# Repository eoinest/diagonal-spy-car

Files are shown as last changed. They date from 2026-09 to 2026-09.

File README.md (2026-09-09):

# Diagonal Spy Car

An open-source, 3D-printable rover using two owned MG90S-style continuous servos, a LOLIN ESP32-S2 Mini, and diagonal drive wheels. Inspired by [Pro Know DIY's micro RC FPV car](https://github.com/proknowdiy/micro_rc_fpv_car_esp-now).

## Complete Blender assembly - revision 0.6.2

Open the [complete Blender model](cad/complete/complete-spy-car.blend) for assembled and exploded scenes, detailed component references, routed wiring, and the removable electronics carrier. The battery, owned large buck and S2 Mini fit in one layer on a **52 x 76 mm deck**. The integral printed axles are preserved. The simplified revision removes the battery-sensing perfboard, its transistors/resistors, ADC capacitor, signal wiring and printed holder. The fuse, small 100 nF S2 bypass and positive-only `J_PWR` remain. Revision 0.6.2 removes the extra 220 µF capacitor, its wires and printed holder. Battery checks are manual; there is no onboard voltage monitoring or low-voltage stop. Revision 0.6.1 corrects the fuse to a rounded epoxy profile and adds axial lead clearances to its holder.

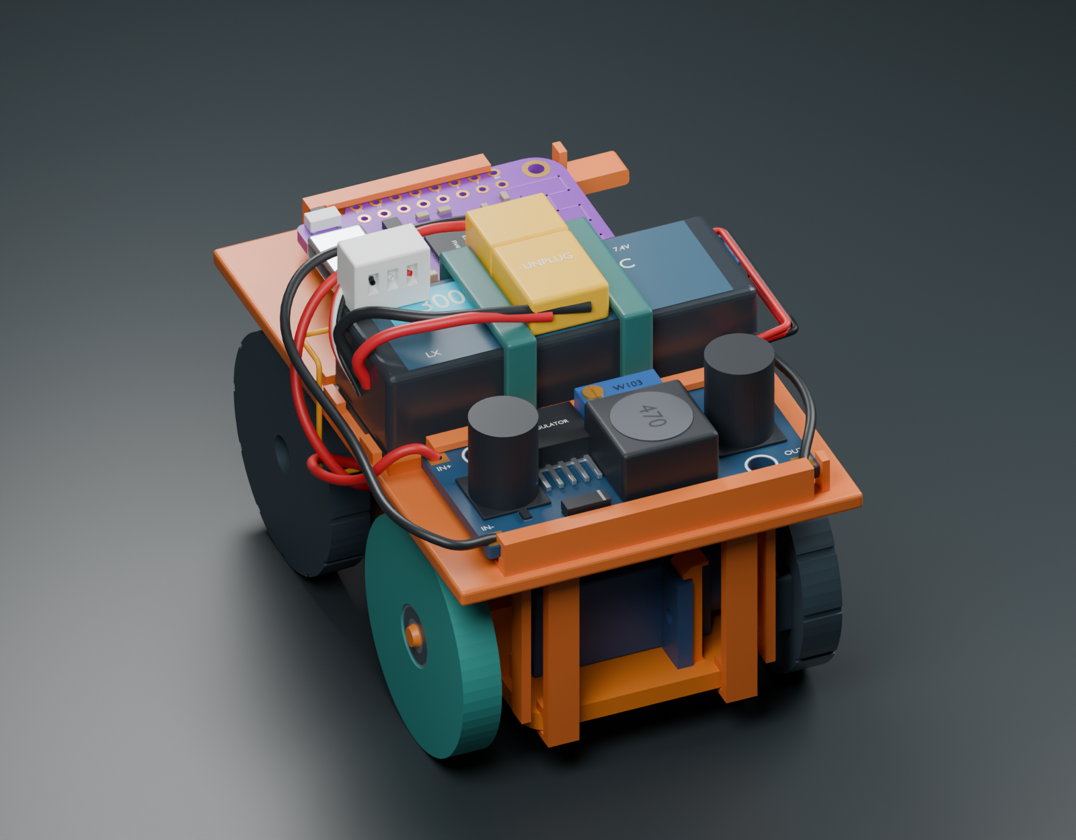
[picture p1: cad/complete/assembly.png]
Complete camera-free car


Get the [new printed parts and assembly instructions](cad/complete/README.md), [dimension assumptions and sources](cad/complete/README.md#what-is-accurate-and-what-still-needs-measurement), and [geometry validation report](cad/complete/validation.json). This is a complete nominal prototype; the owned buck, servo and horn geometry still requires measurements.

## Picture wiring guide and current electronics

Use the [seven-page illustrated wiring PDF](output/pdf/spy-car-wiring-guide.pdf), [step-by-step wiring notes](electronics/wiring.md), and [camera-free electronics BOM](electronics/camera-free-bom.csv). This revision selects the owned large LM2596-style buck at 5.00 V and a Lumenier 300 mAh 2S XT30 battery (48 x 17 x 12 mm). Converter identity and loaded performance still need confirmation; neither owned board supplies LiPo charging or cutoff. The guide includes exact S2 pad callouts, manual per-cell battery checks, USB isolation and connector matching.

**Routine firmware updates use Espressif's bundled HTTPUpdateServer:** after one USB installation and private password setup, hold the S2 Mini's BOOT/0 button for three seconds after normal startup, join `SpyCar-Update`, and upload the receiver application at `http://192.168.4.1/update`. Driving stays locked during updates. No extra power switch or onboard hardware is needed; USB remains for initial setup and recovery. Read the [wireless update instructions and bench verification limits](firmware/README.md#wireless-receiver-updates). This feature is software-tested, not yet verified on the physical car.

## Browser joystick remote

The S2 Mini now serves a simple phone or desktop joystick at **http://spy-car.local/** using the same existing-Wi-Fi + mDNS approach as auto-switch. Hold and drag for proportional forward/reverse, curved turns and spins; release to stop. An optional **SpyCar** Wi-Fi network works away from your router. No app, internet service or second ESP32 is required. The existing handheld remains an optional firmware mode.

Read the [network setup, calibration and testing instructions](firmware/README.md#browser-remote-control). Software and simulated browser checks pass; actual networking and servo behavior still require a wheels-raised test on the car. Firmware defaults keep motion disabled until servo calibration is confirmed.

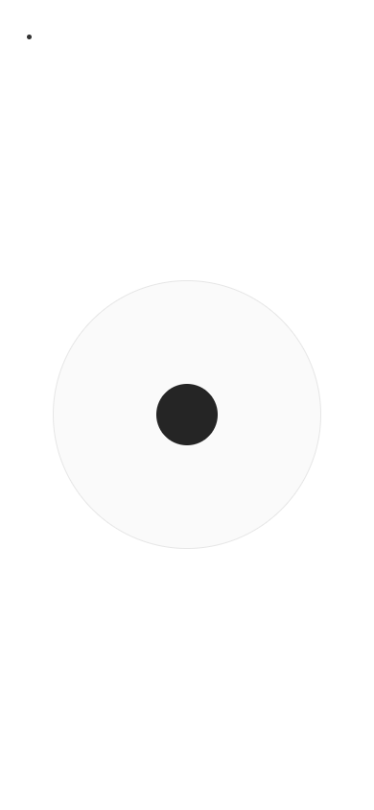
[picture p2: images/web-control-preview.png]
Phone joystick preview using simulated car telemetry


## Earlier mechanical stage: integral printed axles

The latest [revision 0.4 model](cad/rolling/README.md) makes both passive-wheel axles **part of the printed chassis**, with integral shoulders and servo retaining clips. Bearings press-fit into the wheels and onto the stationary pegs. There are **no added screws, nuts, caps or separate spacers** in this mechanical stage: only the owned servos and two MR83ZZ bearings are purchased parts.

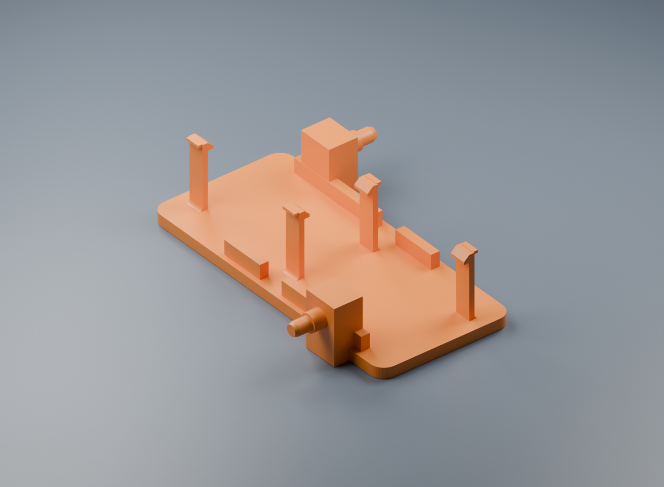
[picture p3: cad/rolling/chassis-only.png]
Chassis with integral printed axles


Open the [wheel-only Blender model](cad/rolling/rolling-chassis.blend), get the [chassis, wheel and two fit-coupon STLs](cad/rolling/README.md), or review [the simplified bearing parts list](docs/passive-wheel-parts.md). The illustrated footprint is approximately **50 × 70 mm** with 30 mm wheels. Printed friction fits and clips need physical validation; the powered wheels remain size envelopes pending their horn attachments.

## Previous step: compact servo bracket

The current direction drops the camera and places the two servo bodies directly alongside each other, with one rotated 180 degrees so their shafts emerge at diagonal corners. The first model is a **30 × 66 mm one-piece bracket** with four mounting-ear screw points. It is a nominal fit prototype; measure the owned servos before relying on the hole positions.

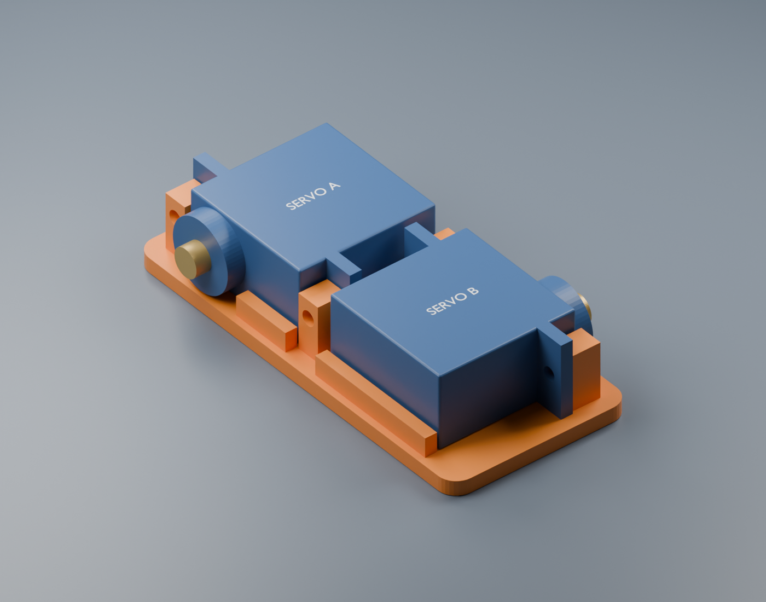
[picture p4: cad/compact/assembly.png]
Compact opposing servo pair


Open the [Blender model](cad/compact/servo-pair.blend), download the [bracket STL](cad/compact/servo-pair-bracket.stl), or read the [compact model notes and parameters](cad/compact/README.md). The [camera-free battery and regulator shortlist](docs/compact-shopping.md) supports the next electronics-layout step. This first bracket has no electronics deck or wheel mounts yet; the complete camera-free assembly above supersedes this first bracket.

## Archived early concept

The original camera-equipped revision used different batteries, regulators and power monitoring. Its [CAD](cad/diagonal-spy-car.blend), [BOM](BOM.md), and [power research](docs/power.md) are historical references. Build from the current [complete assembly instructions](cad/complete/README.md), [electronics BOM](electronics/camera-free-bom.csv), and [firmware instructions](firmware/README.md).

## Rebuilding the current assembly

Follow the [complete assembly rebuild and verification instructions](cad/complete/README.md#rebuild-and-verification). The build scripts regenerate the deck STL and model; `power_update.py` then applies the fuse, connector and harness details and renders the current views. Fit, electrical loading and actual driving still require physical prototype checks.

## License and provenance

Original CAD, scripts, firmware and documentation are released under the **[MIT License](LICENSE)**. Brand names identify compatible purchased parts; no affiliation or endorsement is claimed. This is an original design inspired by the linked project; no upstream code, meshes or PCB files are redistributed. Source links identify which dimensions are published and which are assumptions. See [third-party notes](THIRD_PARTY.md).

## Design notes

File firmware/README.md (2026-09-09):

# Firmware: browser joystick and wireless updates

Original MIT-licensed prototype firmware for an ESP32-S2 Mini car. The car hosts a touch/mouse joystick at **http://spy-car.local/**, with no app, internet connection, or second ESP32 needed. The previous ESP-NOW handheld remains an optional build mode. A separate parked Wi-Fi mode provides browser firmware updates. Arduino-ESP32 **3.x** is required; the LEDC API differs from 2.x. No code from the inspiration repository was copied.

The checked-in configuration cannot arm. Configure Wi-Fi and measure servo neutral first. This simplified POC has no battery-sensing circuit: check both cells with a multimeter before and between short, attended runs. Firmware provides no low-voltage warning or cutoff. Pairing keys, MAC addresses and analog joystick calibration are needed only for the optional handheld. Firmware compilation and host tests do not validate wiring, servo behavior, RF performance, or battery protection on real hardware.

## Browser remote control

This follows the auto-switch project's **existing Wi-Fi + mDNS** arrangement: a readable `.local` name points to the device on the same network. The car uses Espressif's bundled `esp_http_server` WebSocket support and `ESPmDNS`; the page is plain HTML, CSS and JavaScript embedded in the firmware. No extra server, filesystem upload or third-party Arduino library is required.

### Network setup

1. Copy `firmware/receiver_s2/web_config.h` to `web.private.h` in the same folder. Keep `WEB_CONTROL_ENABLED = true` and `WEB_HOSTNAME = "spy-car"`.
2. For the auto-switch arrangement, set `WEB_WIFI_SSID` and `WEB_WIFI_PASSWORD` to your existing **2.4 GHz** Wi-Fi. Connect your phone to that same network, then open **http://spy-car.local/**. If mDNS does not resolve, use the numeric address printed to the receiver's serial console at 115200 baud. Router client isolation and VPNs can prevent access.
3. Alternatively, leave `WEB_WIFI_SSID` empty to create the standalone **SpyCar** network. Set the private `OTA_PASSWORD` as described below, join SpyCar using that password, and open **http://192.168.4.1/** (or the `.local` name where supported). Stay connected when your phone reports no internet. A configured but unavailable home network does not automatically fall back to this AP; select the mode before building.
4. Keep `web.private.h`, `ota.private.h` and the receiver's `config.private.h` with every build. They are ignored by Git and compiled into the application. Do not publish them.

The standalone AP shares its password with the separate update AP. Existing-network mode uses your router's Wi-Fi password instead. The drive page has no login: use a trusted network, because anyone on that network who opens the page can control the car when the controller slot is free. Origin checks and a page token prevent cross-site command injection; they are not user authentication.

### Driving

Hold the joystick and drag. The page first exchanges centered commands to arm, then follows the held gesture. Release to stop; leaving the page or losing the connection also cancels the gesture. Reconnecting never resumes a previous drag. Only one browser can own control at a time; close its tab before switching phones. A vanished controller can be replaced after two seconds without accepted commands.

| Joystick direction | Left powered wheel | Right powered wheel |
| --- | --- | --- |
| Forward / backward | Forward / backward | Forward / backward |
| Right | Forward | Backward |
| Left | Backward | Forward |
| Forward-right | Forward | Slower forward, reaching zero at 45° |
| Center or released | Neutral | Neutral |

Distance from center sets the requested speed, with a 6% center deadzone. The mixer uses `left = y + x`, `right = y - x`, normalizes both together, then applies radial speed. This covers the full circle without calculating an angle. Wheel commands are bounded and retain the conservative PWM range and acceleration ramp. Continuous-rotation servos do not report actual wheel speed: equal commands may drift, and this is not PID speed control.

The browser exchanges commands about every 50 ms with only one normal command awaiting acknowledgment. Each server challenge is single-use and expires after 200 ms; command age starts when that challenge was issued, so delayed TCP traffic cannot masquerade as fresh input. The drive loop disarms after 250 ms without a valid command and runs at a higher task priority than the HTTP server. Explicit stops bypass the movement queue; controller session changes invalidate old queued commands. These are software stop requests, not a certified stopping-time guarantee or a power disconnect.

### First drive and verification

Start with servo power disconnected. Set up the network and confirm the page opens. Copy receiver `config.h` to `config.private.h`; perform the servo-neutral calibration in commissioning steps **4–5** below. The browser shows the missing servo calibration and stays disabled until it is confirmed. No ADC calibration or perfboard is required; GPIO3 and GPIO7 remain unconnected. The minimal page shows connection status, with no battery-voltage readout.

Upload the configured receiver, raise the wheels, and verify forward/reverse, both spins, gradual speed changes and immediate neutral on release. Check a hidden tab, phone Wi-Fi loss, reconnection requiring a fresh gesture, a second browser, and maintenance-mode inhibition. Finally make a slow floor test. The diagonal wheel arrangement still needs sideways tire scrub to turn.

Software verification includes host protocol/gate tests, 15 browser-controller unit cases, phone and desktop layout checks, simulated WebSocket pointer interactions, and an Arduino-ESP32 3.3.11 compile. **The actual ESP32 HTTP/WebSocket service, phone networking and physical servo stopping remain untested on hardware.**

To edit the page, change `receiver_s2/web/`, run `python3 scripts/embed_web_control.py` from the repository root, then rebuild the receiver. `web_assets.h` is generated and committed so Arduino users can build without Python.

To use the previous handheld instead, set `WEB_CONTROL_ENABLED = false` in `web.private.h` and complete all legacy commissioning steps. Browser driving and ESP-NOW driving are mutually exclusive; parked OTA works with either.

## Hardware

| Board | Pin | Connection |
| --- | --- | --- |
| S2 mini | GPIO16 | Left continuous-rotation servo signal |
| S2 mini | GPIO18 | Right continuous-rotation servo signal |
| Original ESP32 DevKit | GPIO32 | Joystick throttle wiper |
| Original ESP32 DevKit | GPIO33 | Joystick steering wiper |
| Original ESP32 DevKit | GPIO27 | Normally-open deadman button to GND; internal pull-up |

The three DevKit connections above are only for the optional handheld. Power its joystick from **3.3 V**, connect grounds, and keep all analog input voltages in range. Servo power comes from the regulated servo rail, never from an ESP GPIO or its 3.3 V pin. See [wiring](../electronics/wiring.md) for the complete power path. No battery divider or sense gate is fitted in this simplified build; do not connect the LiPo directly to a GPIO.

## Build

Install Arduino CLI and the Espressif board package using its [official instructions](https://docs.espressif.com/projects/arduino-esp32/en/latest/installing.html). These commands are run from the repository root. The commands below pin core 3.3.11 for reproducibility; a different 3.x version must be rebuilt and tested.

```sh
arduino-cli core update-index --additional-urls https://espressif.github.io/arduino-esp32/package_esp32_index.json
arduino-cli core install esp32:esp32@3.3.11 --additional-urls https://espressif.github.io/arduino-esp32/package_esp32_index.json
arduino-cli compile --fqbn esp32:esp32:lolin_s2_mini:PartitionScheme=default --libraries firmware/libraries --output-dir firmware/build/receiver_s2 firmware/receiver_s2
arduino-cli compile --fqbn esp32:esp32:esp32 --libraries firmware/libraries firmware/transmitter_esp32
arduino-cli compile --fqbn esp32:esp32:lolin_s2_mini firmware/servo_neutral_s2
```

For Arduino IDE, copy `firmware/libraries/SpyCarProtocol` into the sketchbook `libraries` directory, open the desired `.ino`, select **LOLIN S2 MINI** for the receiver/calibration tool or **ESP32 Dev Module** for the transmitter, and build. If USB serial is used on the S2, enable USB CDC on boot in the board menu. See [WEMOS's S2 Arduino guide](https://www.wemos.cc/en/latest/tutorials/s2/get_started_with_arduino_s2.html) for the boot/reset sequence if upload does not connect.

List attached ports with `arduino-cli board list`; upload each sketch to its own actual port:

```sh
arduino-cli upload --fqbn esp32:esp32:lolin_s2_mini --port YOUR_S2_PORT firmware/receiver_s2
arduino-cli upload --fqbn esp32:esp32:esp32 --port YOUR_ESP32_PORT firmware/transmitter_esp32
arduino-cli monitor --port YOUR_PORT --config baudrate=115200
```

Do not connect computer USB power and the vehicle's external 5 V rail simultaneously without the isolation described in the wiring document. Do not use a placeholder port literally.

## Wireless receiver updates

This uses **Espressif's bundled `HTTPUpdateServer` and `Update` libraries**, pinned with Arduino-ESP32 3.3.11. They supply the browser page, authentication, upload handling, flash writing and reboot. There is no custom upload protocol, storage implementation or update-page UI; the driving page is separate. Our wrapper starts the password-protected AP only in latched maintenance mode. `ArduinoOTA`, also bundled, is an alternative for IDE/command-line network uploads; it is not enabled here.

No new switch, programmer, router, or custom PCB is needed. USB remains necessary for initial installation and recovery. The handheld transmitter is unchanged and still uses USB programming.

### One-time setup

1. Copy `firmware/receiver_s2/ota_config.h` to `ota.private.h` alongside it. Set `OTA_PASSWORD` to a unique random **12–63 character printable ASCII password without spaces**. This ignored file must never be published. The password protects both the Wi-Fi network and browser login; browser username: `admin`. The empty checked-in password disables the network.
2. Keep your existing `config.private.h` containing pairing keys and calibration. All private configuration files, including `web.private.h`, must accompany **every future build**. Settings are currently compiled into the application, not saved separately in NVS.
3. Build with the command above and upload over isolated USB using the existing wiring procedure. Keep **Default 4 MB with SPIFFS** (`PartitionScheme=default`): it contains two 1,310,720-byte application slots. Huge APP and No OTA schemes cannot support this workflow. Changing the partition layout later requires USB.

### Each wireless update

1. Build the receiver with those same private files and partition scheme. The upload file is **`firmware/build/receiver_s2/receiver_s2.ino.bin`**. Do not select a merged image, bootloader, partition table, transmitter, or servo calibration sketch.
2. With USB unplugged and the LiPo disconnected from the car at XT30, check **both cells** with the meter; use a freshly balance-charged pack. Raise the wheels, release the browser joystick (or transmitter deadman), then reconnect the LiPo to power the car through its buck. During initial setup, servos with unknown neutral must have their power disconnected.
3. Boot normally with **BOOT/0 released**, then hold that existing button for **three seconds**. Do not hold it while switching on or pressing RESET: that enters the ROM bootloader. A short press already disarms; the long press locks maintenance mode until restart.
4. Join **`SpyCar-Update`** on your laptop with your private password. Stay connected when warned there is no internet. Open **http://192.168.4.1/update**, log in as `admin`, choose `receiver_s2.ino.bin` in the **Firmware** section, and select **Update Firmware**. Leave the library page's **FileSystem** section alone; the car does not use filesystem updates.
5. Keep power connected until success and restart. The update network disappears; driving starts disarmed and requires the normal fresh deadman sequence. Failed uploads stay parked and can be retried while the network remains available.

The network has a five-minute window from entry. The library handles uploads synchronously, so an active or stalled request can extend that window. Timeout leaves driving locked and **does not disconnect battery power**. Restart to reopen the network; unplug the battery after use.

### Behavior and verification limits

Maintenance blocks incoming commands, stops the browser control server or ESP-NOW, and sets hardware PWM to calibrated neutral before starting the server. The bundled HTTPUpdateServer checks credentials and browser Origin before accepting an upload; Update writes to an inactive application slot and selects it on successful completion. We rely on these standard library behaviors and do not duplicate their parser or storage logic. Their checks cannot determine whether the selected application is the correct car program or free of bugs. Automatic rollback and signed firmware are not configured. Keep USB physically accessible for recovery.

There is **no automatic voltage check before or during an update**. Check both cells with a meter beforehand and use a charged, balanced pack. The ESP32 cannot determine remaining charge in this build and cannot disconnect the battery. Old `BATTERY_*` constants in an existing private config have no effect; remove them when refreshing that file.

Calibrated servos can remain connected for routine OTA, but neutral is a command, not electrical isolation. PWM is interrupted during reboot. Verify the owned servos' behavior with wheels raised. The page uses HTTP within the password-protected local AP, not HTTPS; anyone given the password can replace the firmware.

Bench acceptance: verify button entry, neutral during uploading and reboot, wrong-password rejection, two successive successful updates, interrupted/wrong-file uploads, timeout remaining parked, and fresh arming after restart. Host tests and compilation do not establish these physical outcomes.

References: [Espressif HTTPUpdateServer](https://github.com/espressif/arduino-esp32/tree/3.3.11/libraries/HTTPUpdateServer), [Update](https://github.com/espressif/arduino-esp32/tree/3.3.11/libraries/Update), [ArduinoOTA alternative](https://github.com/espressif/arduino-esp32/tree/3.3.11/libraries/ArduinoOTA), [WEMOS schematic](https://docs.wemos.cc/en/latest/_static/files/sch_s2_mini_v1.0.0.pdf).

## Legacy handheld commissioning

For browser control, use the network setup above and shared calibration steps 4–5 here; skip handheld pairing and analog joystick setup.

1. **Start with servo power disconnected.** Upload the receiver and transmitter in their checked-in state. Their serial status reports the station MAC repeatedly. Keep the car's wheels off the floor during all remaining setup.
2. Copy each sketch's `config.h` to `config.private.h` in the same folder. The private file overrides the example and is ignored by Git. Put the transmitter station MAC in the receiver config and the receiver station MAC in the transmitter config. Keep the channel identical. Generate two independent random 16-byte values for PMK and LMK, put the same pair in both private files, and set `PAIRING_CONFIGURED=true`. Never upload the private files to GitHub.
3. Measure joystick center and both endpoints using the transmitter's raw serial readings. Update minima, centers, maxima, and directions. Power must remain 3.3 V. Adjust deadzone so the untouched stick consistently reads zero. Then set `JOYSTICK_CALIBRATION_CONFIRMED=true`.
4. Find the true neutral of each servo using a servo tester or the supplied `servo_neutral_s2` sketch. The bench sketch accepts serial lines such as `L1500` or `R1500`, emits that pulse for at most five seconds, then removes PWM. Only one output is active. Begin at 1500 µs and adjust in 1–2 µs steps within 1400–1600 until the shaft stops. Record the midpoint of its stopped band. This is an intentional powered bench test: removing PWM is not a guaranteed physical stop for every clone, so keep the XT30 disconnect reachable and unplug power after each test. Do not leave the bench sketch installed for driving.
5. Enter `LEFT_NEUTRAL_US` and `RIGHT_NEUTRAL_US` in the receiver private config. Confirm the units really are continuous-rotation servos. Restore the receiver sketch. Set `SERVO_CALIBRATION_CONFIRMED=true` only after the neutral measurements. Start with the limited ±180 µs range; verify direction with wheels lifted before trying the floor. Reverse a `*_DIRECTION` constant if necessary.
6. Check both cells with a multimeter before the run. Rebuild and upload private configurations. With the stick centered, release the deadman, then press it while still centered. Move the stick only after that sequence. Release the deadman to stop. Confirm radio loss, transmitter reboot, and maintenance-mode inhibition while the wheels are lifted, then make a slow floor test.

Generate local keys, for example, with Python; the resulting values belong only in private config files:

```sh
python3 -c 'import secrets; print(", ".join("0x%02x" % b for b in secrets.token_bytes(16)))'
```

Run twice for independent PMK and LMK values. These are local pairing secrets, not credentials for any online service.

## Behavior and limits

In optional ESP-NOW mode, the transmitter sends encrypted unicast commands every 20 ms. Both peers use an explicit MAC, fixed channel, PMK, and LMK. The receiver checks source MAC, packet size, magic, version, flags, bounds, session ID, and increasing sequence number. Radio reception only queues packets; control runs in the main loop, with at most eight packets handled per iteration. A queue overflow immediately requests neutral, discards the backlog, and disarms. A random session is generated at each transmitter boot. New sessions start disarmed.

Releasing the deadman immediately commands the calibrated neutral. A 250 ms command timeout disarms and requires a fresh release-and-centered, then press-and-centered sequence. A held deadman after reconnect cannot restart motion. A moved stick during an arming attempt cancels readiness. The transmitter has no return telemetry or armed indicator, so verify behavior during commissioning. Radio loss detection includes the main-loop scheduling interval; physical stopping distance depends on the servos and surface.

Normal PWM changes slew by at most 8 µs per 20 ms. Deadman, radio-loss, maintenance, and fault stops bypass that ramp and command neutral. Neutral PWM is a stop request; it does not disconnect servo power. Unplug XT30 for a definitive power stop. Missing PWM while unconfigured is also not a guarantee that every servo variant will remain still when powered.

Battery voltage is **not measured by the car**. The sensing perfboard, divider, transistors, ADC filter and GPIO3/GPIO7 connections have been removed. Check each cell with a multimeter before and between short, attended runs, using the limits and procedure in [wiring](../electronics/wiring.md). A total pack measurement alone can hide a weak cell. There is no software low-voltage stop, warning, or automatic power cutoff; the car continues drawing power while parked. Unplug the XT30 after use and before leaving it unattended. The fuse protects against excess current, not over-discharge.

The diagonal wheel geometry remains mechanically prone to scrub; electronic mixing does not remove that resistance. See [mechanics](../docs/mechanics.md).

## Host checks

```sh
TMPDIR=/private/tmp c++ -std=c++14 -Wall -Wextra -Werror -Ifirmware/libraries/SpyCarProtocol/src firmware/tests/drive_gate_test.cpp -o /private/tmp/spy-car-gate-test
/private/tmp/spy-car-gate-test
TMPDIR=/private/tmp c++ -std=c++14 -Wall -Wextra -Werror firmware/tests/maintenance_gate_test.cpp -o /private/tmp/spy-car-maintenance-test
/private/tmp/spy-car-maintenance-test
TMPDIR=/private/tmp c++ -std=c++14 -Wall -Wextra -Werror firmware/tests/web_control_protocol_test.cpp -o /private/tmp/spy-car-web-test
/private/tmp/spy-car-web-test
node firmware/tests/web_control_ui_test.mjs
python3 scripts/embed_web_control.py --check
```

On Linux use `/tmp` instead of `/private/tmp`. Tests cover default inhibition, neutral arming, deadman release, timeout, duplicate/stale packets, new sessions, rearming, counter/timer wrap, packet validation, maintenance button timing and maintenance staying latched. Web tests additionally cover bounded parsing, radial wheel mixing, expiring single-use challenges, browser arming, pointer cancellation, late acknowledgments and reconnect behavior. These test our gates and UI directly; they do not simulate the standard HTTPUpdateServer, RF, PWM timing, motors, or the power circuit.

API provenance: [Espressif ESP-NOW](https://docs.espressif.com/projects/esp-idf/en/stable/esp32/api-reference/network/esp_now.html), [Arduino-ESP32 LEDC](https://docs.espressif.com/projects/arduino-esp32/en/latest/api/ledc.html). The implementation is original code built against these documented interfaces.

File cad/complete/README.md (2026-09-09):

# Complete camera-free assembly - revision 0.6.2

Open **[spy-car-v0.6.2-no-extra-capacitor.blend](spy-car-v0.6.2-no-extra-capacitor.blend)** for the verified capacitor-free snapshot with the full car framed in Blender. The canonical build output is [complete-spy-car.blend](complete-spy-car.blend). It contains `01 ASSEMBLED`, `02 EXPLODED`, `03 BATTERY DIMENSIONS`, `04 POWER SERVICE`, and `05 CONNECTOR DETAILS` scenes, named component collections, millimetre units, and source/confidence properties on the new electronics objects. The exploded scene hides loose wire curves to expose the parts.

Assembled car

The battery, buck and S2 sit in one layer on a **52 x 76 mm removable printed deck**. This is slightly wider and longer than the wheel-only revision, but avoids stacking the buck above the S2. The main platform underside is 25 mm above the model origin, giving **1.5 mm nominal clearance above the 30 mm wheels**. Inspect [power-validation.json](power-validation.json) for the updated assembled bounds, including reference connectors and routed wires. [validation.json](validation.json) records the regenerated printed-deck checks for revision 0.6.0.

## Extra capacitor removed — revision 0.6.2

The external **220 µF capacitor**, its metal lid, two wires and printed under-deck cradle/end stops have been removed. The converter's fitted capacitors and the small **100 nF S2 bypass** remain. This POC omits extra bulk capacitance pending physical power/load tests.

The saved assembly was patched directly to preserve other geometry; its earlier fuse correction was restored where a stale saved scene had reverted it. [Removal validation](bulk-removal-validation.json) records every removed object and validates the updated deck STL. The model and all current renders use this revision.

## Fuse shape correction — revision 0.6.1

The fuse now has a smooth epoxy-coated body with rounded shoulders, tapered lead exits and a shallow waist matching the family reference photograph. The **7.11 mm body length, 2.80 mm maximum diameter and 0.64 mm leads** follow the [Littelfuse drawing](https://www.littelfuse.com/assetdocs/littelfuse_fuse_251_253_datasheet.pdf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). The contour is photo-informed, not an exact manufacturer surface model; no unverified printed markings are added.

The updated deck has **1.5 mm axial clearance bores** through the fuse-holder end stops. Leads now exit straight before two **1 mm centerline-radius** bends outside the holder. Solder-joint insulation overlaps the lead and wire; all forming and sleeve dimensions are assembly allowances to verify physically. The retained loose holder is not a validated snap fit. Use this revision's `electronics-deck.stl` with the revised lead routing.

The updated power validation measures the body envelope, checks its closed shell, and checks swept lead geometry against rigid components. The rest of the car and its manual battery-check approach remain unchanged.

## Simplified electronics — manual battery checks

Revision **0.6.0** removes the entire battery-sensing circuit: perfboard, two transistors, six resistors, ADC filter capacitor, their leads and four external sensing connections. GPIO3 and GPIO7 are unwired. The deck has been regenerated **without the sensing-board walls, ledges, end stop and retaining tongue**; the battery-strap cutter is 0.04 mm wider to avoid a coplanar mesh seam; use the updated `electronics-deck.stl`.

The battery, buck, S2, servos, bearing wheels and integral-axle chassis retain their existing nominal dimensions and arrangement. This clears the middle underneath the deck; the **52 × 76 mm deck footprint is unchanged** because the battery and boards still occupy the same space.

- Retained: input fuse, 100 nF bypass capacitor, XT30 and positive-only `J_PWR`. No sensing board is hidden in the assembly or exploded scenes.
- `J_PWR` remains a removable positive 5 V wire connection for USB recovery. Its **9.4 × 2.8 × 3 mm mated housing allowance is provisional**; the exact connector is not selected. Ground stays continuous.
- The fuse uses the **7.11 × 2.80 mm maximum body** and **0.64 mm leads** of the candidate Littelfuse 0251004.MXL. The retained loose carrier, insulation, strain relief and rating need physical verification.
- Power distribution uses insulated soldered splices. The 100 nF bypass connects S2 VBUS/GND after `J_PWR`.
- Firmware and joystick no longer measure or display battery voltage. **There is no automatic low-voltage warning, motion stop or cutoff.** Follow the manual per-cell multimeter procedure in the [wiring notes](../../electronics/wiring.md#manual-battery-checks---no-onboard-low-voltage-protection).

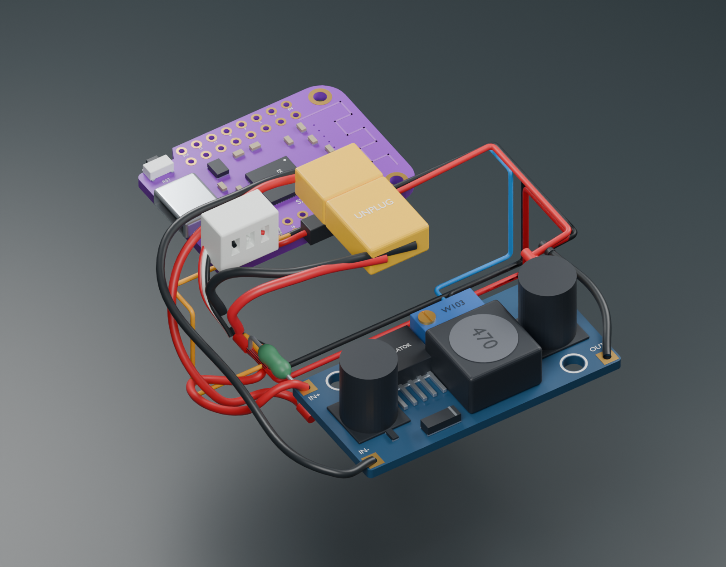
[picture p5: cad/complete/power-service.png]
Power parts with pouch and carrier hidden


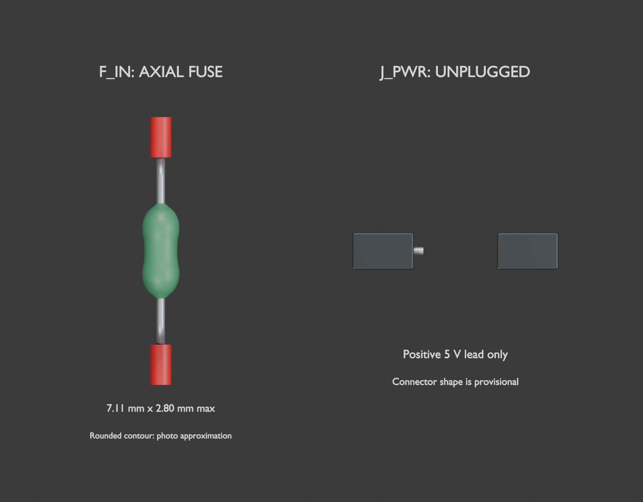
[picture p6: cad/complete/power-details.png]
Enlarged fuse and unplugged positive connector


[Power revision verification](power-validation.json) checks the fuse, J_PWR and relocated capacitor against rigid components, and rejects leftover sensing packages. [Printable-part verification](validation.json) checks deck topology and nominal rigid clearances. [Simplification audit](simplification-validation.json) compares the retained primary component geometry against the saved previous assembly and checks every scene for leftover sensing objects. These checks do not verify flexible wire bends, solder clearances, connector access or physical fit.

The [seven-page wiring guide](../../output/pdf/spy-car-wiring-guide.pdf) has matching instructions. Home-Wi-Fi browser driving works in firmware; updates currently use `SpyCar-Update`. Home-Wi-Fi-first OTA with AP fallback remains planned.

## Battery dimension correction

**Independent audit, September 8:** the saved model and the currently open Blender scene have no battery scaling defect. However, the manufacturer listing (48 × 17 × 12 mm) conflicts with its linked MSDS (13 × 16 × 45 mm, axes unspecified). The current shape is therefore a **provisional packaging envelope**, not a verified replica of the physical pouch. See [the independent audit](battery-audit.md) for measurements and both primary sources. Matching bounds does not establish the correct tapered wrap silhouette.

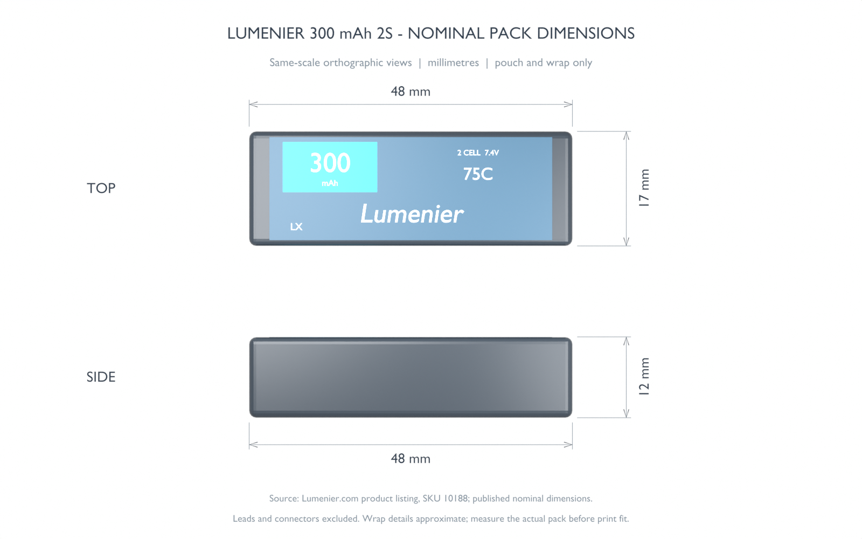
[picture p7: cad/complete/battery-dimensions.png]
Battery in true orthographic views


The selected pack is the **Lumenier 300 mAh 2S XT30, SKU 10188**. Its manufacturer lists **48 mm long × 17 mm wide × 12 mm high**. In the assembled car these are X × Y × Z: the 48 mm length runs across the deck. This is the same pack photographed in the wiring guide; the guide photo is not a scale drawing.

An audit of the previous saved model found a **48 × 17 × 11.84 mm wrap** with a thin label above it. Length and width were already correct. Revision 0.5.1 brings the finished wrap and label to **48 × 17 × 12 mm**, rounds the wrap more softly, and turns the label artwork along the long axis as shown in the product photo. The dimensions scene uses copies of the actual battery geometry at identical scale, without the straps and plugs obscuring its top. Artwork, folds and lead exits remain photo-derived approximations.

The corrected finished pack sits at **Z 28–40 mm**, directly above the 0.8 mm pad. The existing carrier accommodates it: nominal clearance is **0.4 mm at each end stop**, **1 mm per side inside each band**, and **1.2 mm above the pack inside the band**. The printed carrier and bands therefore do not need resizing. These are CAD clearances, not a validated elastic grip or supplier tolerance allowance. Measure the purchased pack before final fit.

The build measures the actual transformed geometry and rejects a deviation greater than **0.01 mm** from the nominal envelope; this computational threshold is not a manufacturing tolerance. Dimensions exclude leads, connectors and padding. Sources: [manufacturer specifications and product photos](https://www.lumenier.com/products/lumenier-300mah-2s-75c-lipo-battery-xt-30), [wiring guide](../../output/pdf/spy-car-wiring-guide.pdf). No published dimensioned manufacturing drawing or measured physical pack is available, so a perfect replica cannot yet be established.

## Included in the model

- The unchanged [revision 0.4 chassis](../rolling/README.md), including its two integral bearing axles and four servo retaining clips.
- Both nominal MG90S-style servo cases, ears, bosses and shafts; two MR83ZZ 3 x 8 x 3 mm bearings; two passive press-fit wheels.
- New powered wheels with keyed pockets for assumed factory double-arm horns, relieved retaining tongues, and center-screw access. The **original horn and supplied servo center screw** remain part of the owned servo assembly. No replacement spline is invented and no new mounting screws are specified.
- Detailed Lumenier 300 mAh 2S battery, large LM2596-style module and LOLIN S2 Mini, including drilled PCB pads, reference mounting holes, USB shell, switches, antenna, IC packages, capacitor markings and PCB labels.
- XT30 mating connector reference, balance connector, removable `J_PWR`, fuse and 100 nF bypass capacitor. No battery-sensing board or components.
- Named power, ground and GPIO wire routes. Battery and board endpoints use the modeled terminal coordinates. These are packaging/service-loop references, **not a replacement for the [electrical guide](../../electronics/wiring.md)** or a production harness drawing.

The camera and external charging/transmitter equipment are not mounted on this camera-free car. The receiver now supports the phone/browser joystick; the separate ESP-NOW handheld is optional. Configure Wi-Fi, commission servo neutral and check both battery cells with a multimeter before driving.

## What is accurate, and what still needs measurement

| Feature | Model basis |
| --- | --- |
| Battery pouch envelope | Provisional **48 x 17 x 12 mm** for the selected [Lumenier pack](https://www.racedayquads.com/products/lumenier-300mah-2s-75c-lipo-battery-xt-30). Lead lengths, exit shape, wrap/seams and exact connector subtype remain approximations. |
| S2 PCB | Official **34.3 x 25.4 mm** outline, **2 mm holes** and **20.4 mm transverse hole spacing** from [WEMOS](https://docs.wemos.cc/en/latest/_static/files/dim_s2_mini_v1.0.0.pdf). Hole Y, corner/notch details and component locations are image-derived nominal assumptions. |
| S2 headers | Nominal 2.54 mm pitch, columns at X +/-11.43 and +/-8.89 mm before rotation, supported by official photographs and the [KiCad footprint contribution](https://gitlab.com/kicad/libraries/kicad-footprints/-/merge_requests/2904). These coordinates are not fully specified in the WEMOS mechanical drawing. |
| S2 main IC | **7 x 7 x 0.85 mm nominal** QFN package from [Espressif](https://documentation.espressif.com/esp32-s2_datasheet_en.pdf). PCB thickness 1.6 mm, USB and other package heights are unmeasured assumptions. |
| Owned buck | **43 x 21 x 14 mm provisional envelope**, based on a [comparable manufacturer's module](https://wiki.kamamilabs.com/index.php?title=KAmod_LM2596), with component arrangement informed by the user's photograph. Other generic modules differ; no measurement or readable IC marking establishes this exact board size/type. |
| Servos and horns | Inherited nominal servo geometry; **not measured clones**. The assumed 20 x 5 x 2 mm horn and 7 mm hub require verification. Factory screw dimensions are illustrative; actual horn/spline engagement controls the fit. |
| Bearings | Nominal MR83ZZ envelope. Shield detail is illustrative; internal rolling-element geometry is not modeled. |
| Small packages and connectors | The axial fuse follows the published body/lead dimensions; other packages and connectors are packaging references. The fuse, capacitor packages, solder heights and wire bend radii must follow the actual purchased parts. The user's yellow pigtails have not been established as XT30 rather than XT60. |

This is a complete **nominal assembly**, not an exact scan or a claim of physically tested fit. Object properties retain the distinctions rather than presenting decorative detail as measurement evidence.

See the [assembly parts list](parts.csv) alongside the [electrical BOM](../../electronics/camera-free-bom.csv).

## Printed parts and assembly

1. Keep the [existing chassis and passive wheel STL files](../rolling/README.md), including both bearing/axle fit coupons. Axles remain integral to the chassis.
2. Print [electronics-deck.stl](electronics-deck.stl) in PETG as a fit prototype. Four independent end fingers wrap around the base; upper ledges carry the weight and lower hooks prevent lift. End-local guides locate it sideways. The tall fingers, underdeck holders and rail overhangs require an intentional support/orientation plan; inspect the slicer preview before printing.
3. Install the fuse under the deck. Its holder remains; the sensing-board holder and external capacitor cradle have been removed. Leave service slack so the deck can be removed. Actual component heights must fit the verified rigid clearances.
4. Slide the buck and S2 into their board-edge rails from the open end, before attaching the harness. PCB retention is a nominal friction fit with a far-end stop. Inspect underside solder clearance, button access and edge contact on the delivered boards; do not force a board into the rails.
5. Add 0.8 mm protective padding under the battery. Print **two** [battery-band-tpu.stl](battery-band-tpu.stl) loops in TPU; their slots and clearances retain the pack without a rigid high-force clamp on the pouch. Check the actual pack with its wrap and leads. The model does not imply that PETG is a substitute for these flexible loops.
6. Use [powered-wheel-left.stl](powered-wheel-left.stl) and [powered-wheel-right.stl](powered-wheel-right.stl) only after checking the assumed horn pocket against the supplied horns. Retaining tongues have axial relief and rounded lead-ins, but insertion force, fatigue and torque retention are untested. Keep the supplied horn screw accessible through the wheel center; do not force or replace the servo spline with printed teeth.
7. Use the labeled wiring guide, not color alone, to connect the harness. Leave USB and the XT30 disconnect accessible. Neither the buck nor the model supplies battery charging or low-voltage disconnection.

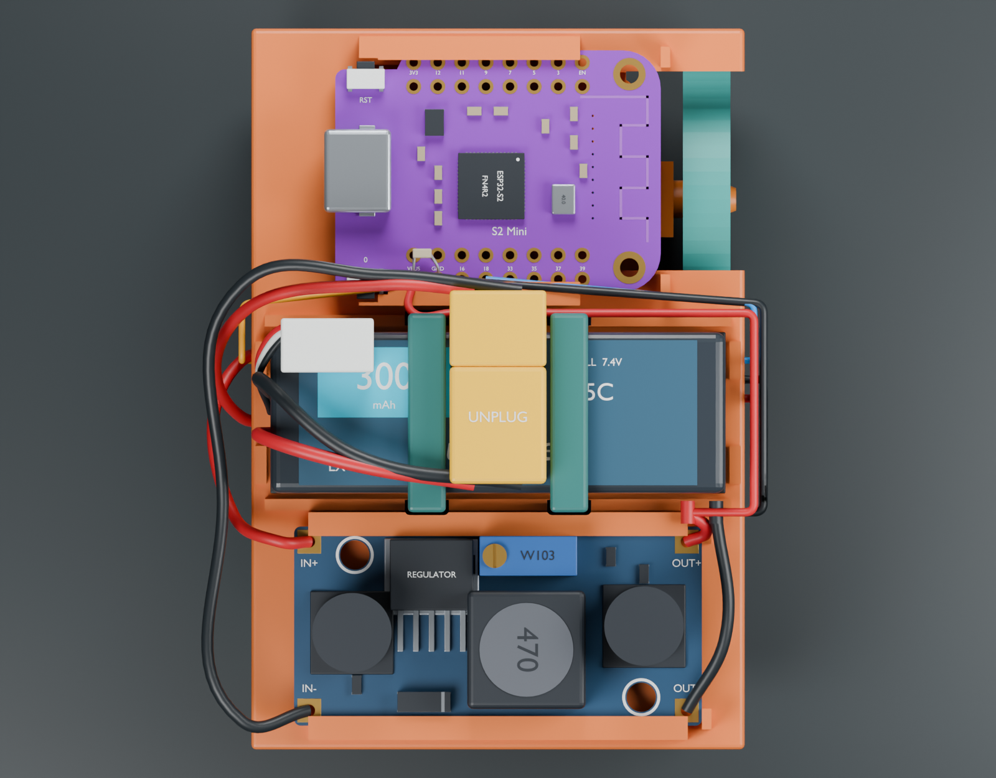
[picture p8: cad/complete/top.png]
Plan view

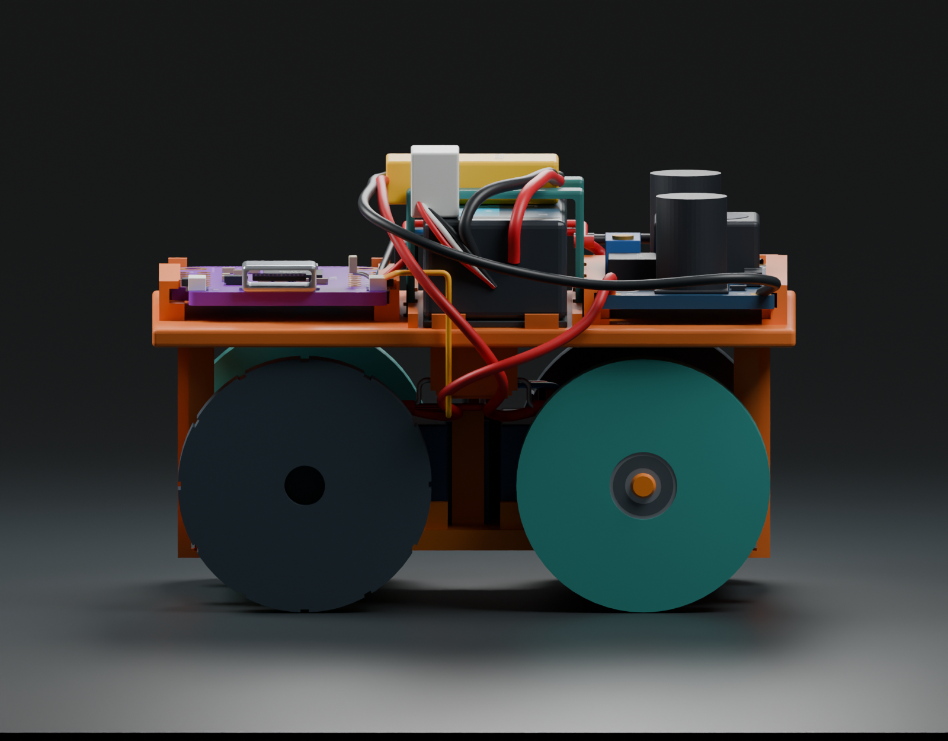
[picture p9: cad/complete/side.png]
Side view

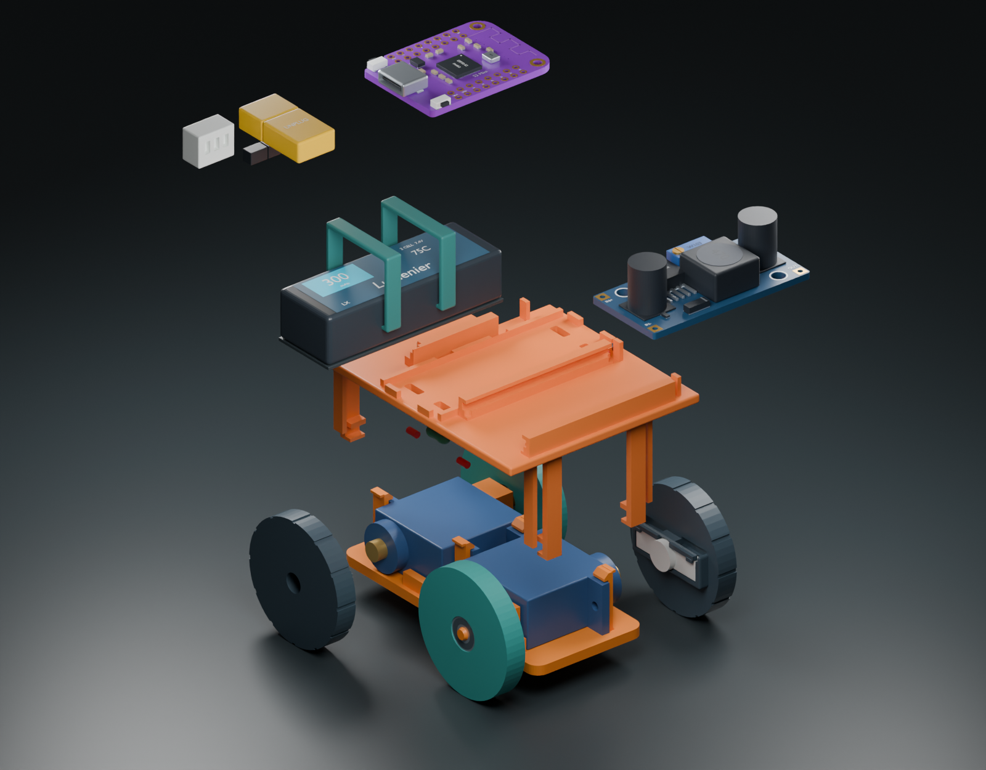
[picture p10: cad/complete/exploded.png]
Exploded assembly


## Rebuild and verification

To compare against a saved previous complete assembly, run Blender with `--python cad/complete/verify_simplification.py -- --before /absolute/path/to/previous.blend`. This checks retained primary geometry and absence of sensing components without modifying the model.

```sh
/Applications/Blender.app/Contents/MacOS/Blender --background --python-exit-code 1 --python cad/complete/build.py
/Applications/Blender.app/Contents/MacOS/Blender --background --python-exit-code 1 --python cad/complete/power_update.py
```

To remove the external capacitor from an older saved assembly, run `remove_bulk.py` first, then `power_update.py`. The base builder already omits it.

`power_update.py` can also run by itself against the existing saved assembly; it preserves mechanical meshes and modifies the power references. Back up local work before any full `build.py` rebuild. Add `-- --skip-renders` to either command to skip PNGs. For the full builder, this regenerates geometry, STL checks and the Blender file without PNGs. The builder reads the saved revision 0.4 model and does not overwrite it. To use a separate known base without importing local chassis edits, append `--base-model /absolute/path/to/base.blend` after `--`; `validation.json` records its SHA-256. Revision 0.6.0 used the committed rolling base and preserved the separately modified local rolling model. `parameters.json` supplies the new component envelopes and placement; detailed mating features and routing are also design constants in `build.py`. Changing a component requires updating its mount and revalidating, not only changing one dimension.

The build checks exported STL topology using the exact serialized float32 coordinates, positive volume, one connected component, winding, degenerate faces and closed edges. Boolean intersection checks cover the new printed mounts, inherited rigid assembly, primary electronic models, factory horn references, and selected rigid accessory packages. Internal decorative layers within one purchased component intentionally overlap and are not a manufacturing representation.

Static checks do not validate print tolerances, snap insertion, dynamic wheel runout, strength, heat, antenna performance, wire chafe, electrical behavior or service access with actual plugs. Those remain physical prototype checks.

The wiring PDF was corrected in commit `582252d`: in the supplied upright buck photograph, **IN+ is lower left and IN- lower right**. Both positive terminals are on the left before the board is rotated in this assembly. The current model and guide use that corrected mapping.

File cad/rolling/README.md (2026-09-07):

# Integral printed axles and press-fit wheels — revision 0.4

The axles are now **part of the chassis itself**. One continuous printed solid includes the base, two axle supports, two solid bearing journals, their inner-ring shoulders, and four clips that retain the servo tabs. The earlier metal axle screws, nuts, bearing caps, cap screws and separate spacers have been removed.

The only purchased mechanical components for this stage are **the two owned servos and two MR83ZZ bearings**. The moving wheels are separate printed parts. Electronics are outside this mechanical-stage parts list; the powered-wheel horn interfaces remain a later step.

One printed chassis, including both axles and all four servo clips

## How the wheels fit

Each passive wheel has an **8.0 mm nominal bearing pocket**, 3.2 mm deep. The bearing outer ring is friction-fit into that pocket, against a ledge that touches only its outer rim. There is no retaining cap. The bearing inner ring is friction-fit onto the chassis's **3.0 mm nominal solid journal**. A tapered tip guides it on, and an integral 4 mm diameter shoulder locates its inner ring.

The bearing provides the rotation. The chassis, axle and bearing inner ring stay stationary; the wheel and outer ring turn together. Both friction fits must retain the assembly axially. There is **no separate end lock**: a loose fit can let the wheel or bearing slide off. Nominal CAD contact is not proof of a working press fit.

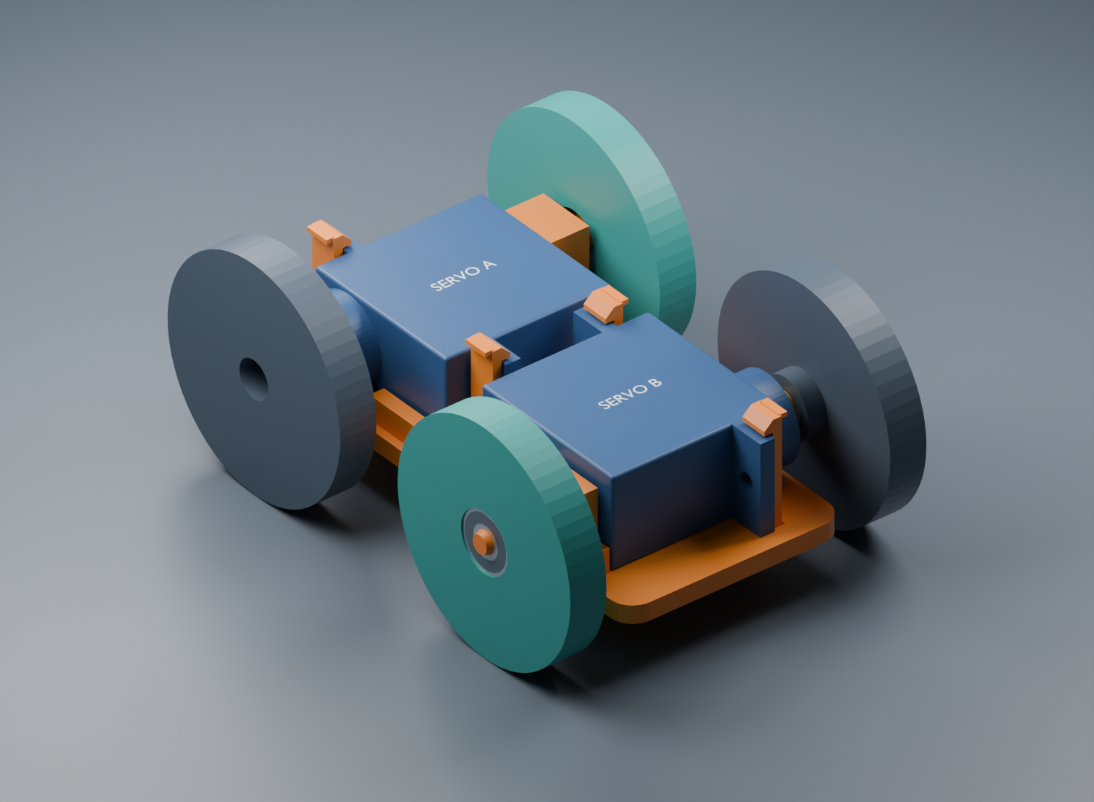
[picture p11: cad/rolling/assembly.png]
The revised four-wheel arrangement


The front-right free wheel shares Y = +20 mm and Z = 8.5 mm with the front-left servo shaft. The rear-left free wheel shares Y = -20 mm and Z = 8.5 mm with the rear-right servo shaft. Both front and rear pairs therefore lie on common X-axis lines, without an axle physically passing through a servo.

Wheel diameter is 30 mm, with 44 mm between tread centers and a 40 mm wheelbase. The nominal illustrated envelope is approximately **50.2 × 70 × 30 mm**. The chassis including its integral pegs is **50.2 × 66 × 16.7 mm**. All dimensions inherit the unmeasured servo assumptions from the [original compact model](../compact/README.md).

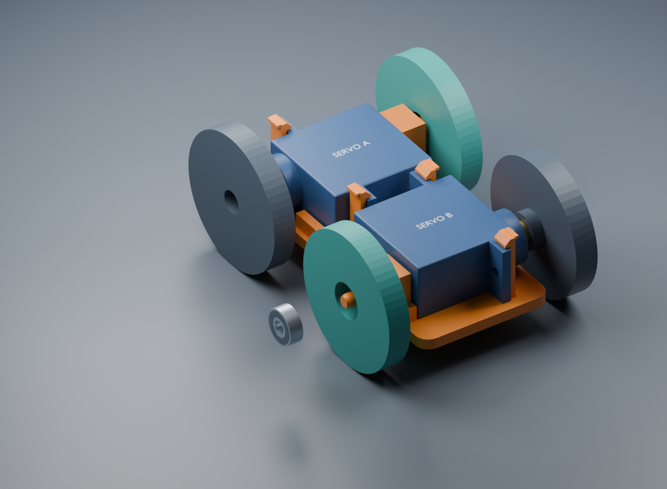
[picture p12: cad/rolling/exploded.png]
Exploded view: only wheel and bearing separate from the integral chassis axle


## Servo retention

Four integral cantilever clips replace the four servo mounting screws. Each hook overlaps its assumed mounting tab by 1 mm, with a 0.3 mm vertical gap above the tab. The stems have outward root reinforcement, insertion ramps and small outward release tabs. Existing low locating rails and the clip positions constrain the cases.

These clips are an **unbuilt fit prototype**. Their static clearances have been checked, but insertion force, flex, layer strength, retention and repeated removal have not been tested. Gently flex the clips outward to install or release the tabs; do not force an incorrectly sized case past them. Adjust the parameters to measured servo tabs if needed.

## Files and print quantities

Open [rolling-chassis.blend](rolling-chassis.blend) to edit the full assembly. Geometry settings are in [parameters.json](parameters.json), with source in [build.py](build.py).

| File | Quantity | Purpose |
|---|---:|---|
| [rolling-chassis.stl](rolling-chassis.stl) | 1 | One-piece chassis, integral axles and servo clips |
| [passive-wheel.stl](passive-wheel.stl) | 2 | Identical moving wheels, bearing pockets open upward in the STL |
| [bearing-fit-coupon.stl](bearing-fit-coupon.stl) | 1 initially | Pockets 7.9 / 8.0 / 8.1 mm, starting at the notched end |
| [axle-fit-coupon.stl](axle-fit-coupon.stl) | 1 initially | Horizontal journals 2.9 / 3.0 / 3.1 mm, starting at the notched end |

Only the chassis and wheels are installed prints; the two coupons are test pieces. Purchase **two MR83ZZ bearings, 3 × 8 × 3 mm**. See the [current mechanical parts list and bearing source](../../docs/passive-wheel-parts.md). Old cap/spacer STLs have been removed from this directory; the earlier screw-based revision is retained in Git history.

## Print and fit before assembly

Use the same material, layer settings, orientation and support strategy for the coupons and final parts. PETG is the first prototype material proposed for the flexible clips; this is not a validated material/process specification. A 0.2 mm layer height and four perimeters are starting settings for the larger parts.

**The horizontal axles and hook undersides need removable slicer supports.** Inspect the preview and ensure the 3 mm journals are actually supported. Remove supports carefully without levering against the small pegs, and clean their bearing surfaces. The integral axles cannot be replaced individually if broken. Printing a vertical test peg would not reproduce the supported horizontal surface of these axles; use the supplied coupon.

1. Test the bearing outer ring in the wheel-pocket coupon, pressing only on the outer ring. Choose a snug fit that holds it without deforming the bearing or letting the outer ring rotate loosely in the pocket. Change `wheel.bearing_seat_diameter` and rebuild if necessary.
2. Test the bearing inner ring on the horizontal peg coupon, pressing on the inner ring. Choose a fit that seats gently but resists slipping off and spinning on the axle. Do not force a fit that bends or cracks the peg. Change `axle.journal_diameter` and rebuild if needed.
3. Verify the actual bearing's inner-ring contact land clears the 4 mm printed shoulder. The 7 mm opening through the wheel clears that stationary shoulder and the rotating bearing's center region.
4. Print and check the chassis clips against both actual servos before engaging them fully. Release the tabs outward during fitting; avoid repeated flex cycles until fit is established.
5. Fit each bearing into its wheel using outer-ring pressure. When seating the wheel/bearing assembly on a chassis peg, apply installation force to the inner ring, not through the wheel and bearing balls. Do not hammer the assembly onto the printed axle.
6. Spin both wheels and check for shield rubbing, binding, tilt and axial looseness. Gently pull on the wheel to confirm that neither friction fit releases. Repeat after sitting assembled and after a short low-speed test, since a printed fit can relax over time.

The dark powered wheels and short horn-interface shapes are **size envelopes only**, with no powered-wheel STL or finalized horn attachment. Their tread diameter must match the free wheels so all four touch the same ground plane. Four fixed-direction wheels still rely on sideways tire scrub to turn.

## Verification and rebuilding

[validation.json](validation.json) reports four closed, connected STL solids with correct winding and no unintended nominal intersections. It distinguishes any deliberate bearing press-fit overlap from unrelated collisions. This checks geometry, not friction force, clip deflection, creep, support removal or loaded strength. The servo dimensions and bearing internal face details remain nominal/assumed.

```sh
blender --background --python-exit-code 1 --python cad/rolling/build.py
python3 cad/rolling/mesh_checks.py
```

Run from the repository root; on macOS use `/Applications/Blender.app/Contents/MacOS/Blender` if needed. Add `-- --skip-renders` to regenerate geometry and checks only. The compact Blender file supplies the nominal servo geometry; its old screw posts are removed by this generator and are absent from the current STL.

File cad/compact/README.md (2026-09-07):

# Compact opposing servo pair — first fit model

This follows the side-by-side arrangement in the user's sketch: both servo bodies share the same lateral centerline, in two adjacent front/back lanes. The second servo is rotated 180 degrees about the vertical axis. Their output shafts point outward at diagonal corners. Original mounting ears remain intact.

Assembled nominal servo pair

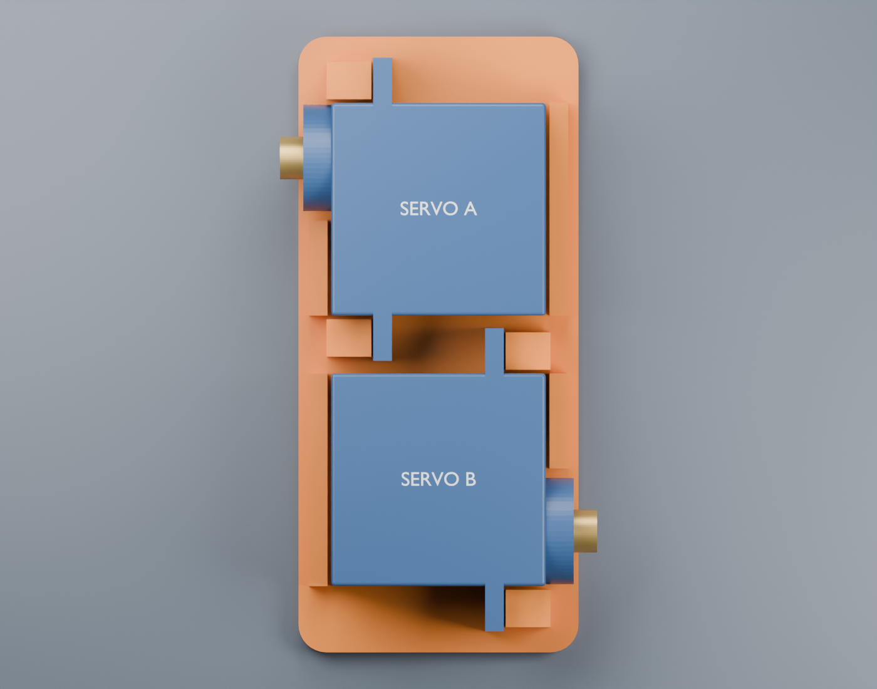
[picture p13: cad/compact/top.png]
Top view of the opposing shafts


## Files

- [servo-pair.blend](servo-pair.blend): editable Blender assembly, with separate collections for the single printed bracket, servo A, servo B, labels and studio.
- [servo-pair-bracket.stl](servo-pair-bracket.stl): only the bracket, in millimetres, flat underside at Z=0.
- [parameters.json](parameters.json): adjustable component assumptions and bracket dimensions.
- [build.py](build.py): source generator, STL export and nominal clearance/topology checks.
- [validation.json](validation.json): generated dimensional and geometry report.

## Geometry

The bracket is **30 × 66 × 11.5 mm**, with a 2.4 mm floor. The nominal servo assembly is **34 × 66 × 14.6 mm**, including bare output shafts, excluding horns, screws, wiring and wheels.

Cases occupy adjacent lanes separated by 29 mm center-to-center. This leaves 1.35 mm between each inner mounting-tab tip and the neighboring case. Shaft tips sit at X/Y coordinates (-17, +20) and (+17, -20) mm. Both shaft centerlines are 8.5 mm above the bracket underside. Front is +Y; the shafts point along opposite X directions, parallel to one another.

Four low locating rails provide 0.4 mm clearance beside the nominal cases; two rails have openings around the output bosses. Four printed posts align with the assumed mounting-ear holes. Their 2.4 mm screw-clearance holes run horizontally along X. Hardware is not printed into the STL.

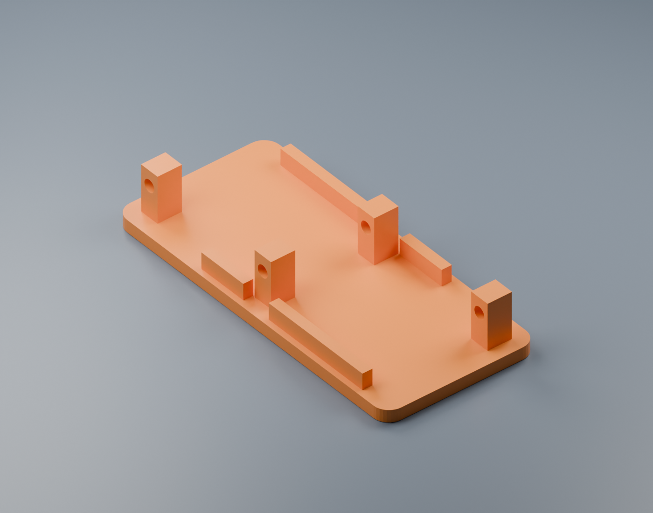
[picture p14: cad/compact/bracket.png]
The one-piece bracket


This is a **fit prototype**, not an exact replica of the owned servo clones. The body-height assumption, mounting-ear thickness/position, hole pitch, shaft offset and cable exits need checking against the actual servos. There is no electronic deck, wheel hub or passive wheel mount in this first model. The floor width reserves clearance for later wheels; wheel and horn fit still requires a separate check.

## First print and assembly

Print the STL flat underside down. A practical starting point is 0.2 mm layers and four perimeters with a 0.4 mm nozzle. Inspect the slicer preview around the small horizontal holes; clean out sagging plastic if necessary. The first print is for checking fit before a loaded driving test.

1. Seat both servos in the orientation shown, without forcing their cases or tabs. Check the cable exits and body width first.
2. Check all four ear holes against the printed posts. Assumed ear-hole pitch is 27.6 mm; change the parameters and reprint if it differs. Do not force screws through misaligned ears.
3. Trial-fit M2 through screws, washers and nuts if the actual ear holes accept M2. The nominal post + gap + ear stack is 7.0 mm before washers and nut; screw length must be selected against the measured hardware stack. Screws, nuts and tool-access envelopes are not yet modeled or validated.
4. Tighten gently, only enough to retain the case. Confirm the shafts turn without touching the bracket. Check that neither servo cable is pinched.

Retaining the supplied ears is the intended attachment. If the clone's tabs differ substantially, update the model rather than cutting the tabs off. The posts are deliberately small for this compact arrangement; strength and fatigue have not been tested.

## Rebuild

From the repository root:

```sh
blender --background --python-exit-code 1 --python cad/compact/build.py
```

On macOS the Blender executable can be `/Applications/Blender.app/Contents/MacOS/Blender`. Add `-- --skip-renders` for geometry/export/validation only. This generator does not modify the earlier revision 0.1 assembly.

The generator checks that the bracket has one connected component, positive volume and zero non-manifold edges; that the bracket does not intersect the nominal servo solids; and that the two servos do not intersect one another. The model checks do not establish measured fit, print strength, cable clearance, screw/nut access or driving performance. Diagonal drive will require sideways tire scrub during turns.

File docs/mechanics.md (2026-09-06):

# Mechanical design and its limits

This is a dimensioned first prototype for two continuous-rotation micro servos driving the front-left and rear-right wheels. The other two corners need low-friction supports. The supplied CAD is an editable design and fit-check model; it is not an exact scan of the owner's components or a physically validated production chassis.

## What was found locally

A filename inventory searched `~/Documents/dev/playground`, then the wider `~/Documents/dev`, including hidden and ignored files while excluding dependency, build, and Git internals. No MG90S or S2 mini component CAD was found. Unrelated enclosure `.blend`, `.stl`, and `.scad` files existed outside playground. No existing component model was copied into this project. Files hidden inside archives or named without a recognizable CAD extension could still exist.

## Reference dimensions and fidelity

| Part | Published nominal dimensions | CAD confidence |
| --- | --- | --- |
| TowerPro MG90S reference | 22.8 × 12.2 × 28.5 mm; manufacturer's second table uses width 12.4 and height 28.4 mm | Reference envelope only; continuous-rotation clones can differ |
| LOLIN S2 mini v1.0.0 | PCB outline 34.3 × 25.4 mm | Manufacturer outline; verify actual board revision and installed headers |
| Servo horn, spline, screw | Use the horn and center screw supplied with each actual servo | Must measure; no assumed spline compatibility |
| Battery, regulator, camera | See BOM and power documentation | Mounts must match the ordered variant including wiring and connectors |

Sources: [TowerPro MG90S](https://towerpro.com.tw/product/mg90s-3/), [WEMOS S2 mini](https://www.wemos.cc/en/latest/s2/s2_mini.html), and [official S2 mini dimension drawing](https://www.wemos.cc/en/latest/_static/files/dim_s2_mini_v1.0.0.pdf).

The MG90S product name alone does not establish that a servo rotates continuously. Confirm that the owner's units have speed/direction control around a stopped neutral. The reference dimensions do not establish the body-only height, shaft offset, mounting-ear hole spacing, or spline geometry of those units. Any such CAD detail is an explicit modeling assumption until measured. A realistic render does not increase dimensional confidence.

## Diagonal drive means tire scrub during turns

The proposed front-left/rear-right arrangement preserves the requested layout. With conventional wheels pointing forward, it must skid sideways while turning. Adding casters at the other corners removes their steering resistance but does not remove the sideways scrub of the powered wheels.

This follows directly from planar rigid-body kinematics. Define forward as `x`, left as `y`, and yaw rate as `ω`. At each conventional wheel contact, the no-side-slip condition is:

```text
v_y + ω x_front = 0
v_y + ω x_rear  = 0
therefore ω (x_front - x_rear) = 0
```

When the powered wheels are separated front-to-back, both conditions can hold only for zero yaw. Any actual turn therefore needs lateral slip, compliance, or steering. For a turn around the midpoint, each wheel's lateral scrub speed is `|ω| × half the front/back separation`. Its commanded forward rolling speed depends on the left/right spacing. A long wheelbase and narrow track make scrub particularly severe. This is an engineering derivation, not a tested performance claim.

Build the diagonal arrangement as a smooth-floor experiment. Begin with narrow, modest-grip tire contact patches and slow acceleration. Check both turning directions because diagonal load transfer and servo mismatch can produce different behavior. A tire grippier than necessary increases turning load. Do not assume it will turn on carpet merely because it drives straight there.

Two conventional powered wheels on a shared transverse axle give normal differential drive and are the straightforward fallback if the diagonal prototype scrubs or stalls excessively. Another geometric solution keeps opposite-corner contacts but rotates both wheel planes so their common axle direction lies along the diagonal joining those contacts; the vehicle's rolling direction then changes relative to its rectangular body. Neither alternative is implemented automatically: choose a revised layout explicitly before modifying the chassis.

## Supports, weight, and height

Two diagonal contact points alone cannot form a stable support polygon. Use the two opposite corner supports shown in the prototype and keep the battery low, approximately central. All four contacts should meet a flat surface without unloading a drive wheel. Rigid four-point support can rock; adjust shims or use slightly compliant mounting to keep both powered wheels loaded. Avoid pushing on a LiPo pouch to obtain compliance.

A purchased ball caster is an optional upgrade from printed sliding feet. For example, the [Pololu 3/8-inch plastic ball caster](https://www.pololu.com/product/950) is approximately 10.2 mm tall without spacers, with approximately 13.5 mm hole spacing and included spacers for height adjustment. Its manufacturer supports #2 or M2 mounting hardware. Check the actual drawing and stock before adapting a mount. This part is not a drop-in promise for a generic printed foot, and a printed captured sphere should not be assumed to roll like a manufactured ball caster.

Match support contact height to the assembled wheel radius, hub offset, chassis thickness, and servo axis height. A nominal wheel diameter is not sufficient: tire compression and printer shrinkage change the final ride height. Leave clearance around rotating wheels and their horn screws, including small wheel wobble.

## Wheel attachment

Retain the original servo horn as the spline interface. Attach a printed wheel to that horn with two small through-fasteners or appropriately sized screws through measured horn holes. Keep a central access hole large enough to fit a screwdriver onto the original horn retaining screw. The small center screw retains the horn axially; the spline transmits motor torque. It must not be the only friction clamp driving an unsplined printed wheel.

Do not force a generic micro-servo wheel onto an MG90S shaft. For example, [Pololu's micro-servo wheel](https://www.pololu.com/product/4914) specifies a particular 21-tooth, 4.8 mm spline for compatible servos; that does not establish compatibility with these MG90S units. A purchased horn supplied with the servo avoids relying on a printer to reproduce tiny spline teeth.

Use two opposing horn holes when practical to reduce eccentricity. Print and test one wheel/horn coupon first. Adjust hole positions to the measured horn. Retain the original center screw and check engagement by hand; do not substitute an unverified screw length or pitch. Leave the wheel close to the case while maintaining clearance to reduce shaft bending load. Do not use glue as the only wheel retention.

## Assembly and print strategy

1. Measure the components using the [measurement checklist](measurement-checklist.md), then update the CAD parameters. Print small fit coupons before the full chassis.
2. Print the chassis and rigid brackets in PLA for the first fit check or PETG if desired. A 0.4 mm nozzle, 0.2 mm layers, four perimeters, and approximately 25% infill are initial slicing choices, not validated strength specifications. Orient broad flat faces on the bed; inspect the slicer's support and bridge preview.
3. Use the actual servo body as a fit gauge without forcing it into a tight pocket. Aim initially for approximately 0.25–0.40 mm clearance per mating side, adjusted for the printer and material. Strap mounts accommodate clone variation; positively restrain rotation and cable strain.
4. Secure the electronics using the designated retainers or removable straps, with an insulating layer under solder joints. Keep USB, reset/boot buttons, switch, charge disconnect, and horn screws reachable. Leave space at the S2 antenna end and around the camera/VTX for heat and wiring.
5. Mount the battery in a padded tray with a soft strap. Do not drive screws toward the pouch or clamp it rigidly. Keep the removable battery connector accessible.
6. Attach wheels, adjust support height, then test with wheels lifted. Confirm neutral, direction, failsafe, and supply behavior before a slow floor test.
7. After a short drive, inspect wheel screw retention, bracket movement, cable abrasion, servo temperature, turn behavior, and brownouts. Stop and revise the mount or geometry if a powered wheel binds, lifts, or stalls.

## Acceptance before calling the car build-ready

- Actual parts fit without stressing the battery, PCB, connectors, or servo case.
- Both powered wheels can rotate fully without chassis or wire contact.
- The chassis rests stably and both powered wheels retain traction.
- Forward, reverse, and both turns work on the intended floor at low speed.
- Lost radio contact and a released deadman stop motion promptly.
- Loaded turn current and battery/regulator temperature are measured within the selected electrical limits.

The last four items require real hardware. They cannot be certified by a Blender render or mesh validation.

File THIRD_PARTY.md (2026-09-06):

# Provenance

This repository contains original design scripts, nominal reference models, printable geometry, firmware and writing. It does not redistribute third-party product meshes, upstream Gerbers, code, images, schematic PDFs or downloaded toolchains.

Inspiration: [proknowdiy/micro_rc_fpv_car_esp-now](https://github.com/proknowdiy/micro_rc_fpv_car_esp-now), MIT licensed, and its linked [build video](https://www.youtube.com/watch?v=aJbycyJAl0k). See the commit-specific references in [reference-project.md](docs/reference-project.md).

Component dimensional and electrical facts are attributed in [component-sources.md](docs/component-sources.md), [power.md](docs/power.md), [mechanics.md](docs/mechanics.md), and [wiring.md](electronics/wiring.md). Decorative CAD geometry is original and approximate. Product marks are descriptive only.

External build dependencies are not vendored: Blender, Arduino CLI, Espressif Arduino-ESP32 and its bundled dependencies. They retain their own licenses. Consult the upstream distributions when modifying or redistributing those dependencies.

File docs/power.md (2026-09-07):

# Historical battery and power proposal

> **Historical design — superseded for the current build.** This page preserves the earlier Tattu 450 mAh / Pololu 4872 / FPV-camera proposal. Its parts, capacitor values, charging-current example, current budget and hardware-cutoff settings do not apply to the current camera-free selection. The current build uses the owned large LM2596-style buck, a Lumenier 300 mAh 2S XT30 pack, external 220 µF / 10 V plus 100 nF starting decoupling, and manual battery disconnection with per-cell monitoring. Use [current wiring](../electronics/wiring.md), [current camera-free BOM](../electronics/camera-free-bom.csv), and [picture wiring guide](../output/pdf/spy-car-wiring-guide.pdf). No battery undervoltage cutoff has been verified on the owned converter.

Design proposal; **not electrically bench-validated**. Sources checked 2026-09-05 (Pacific time). Prices exclude shipping/tax and are snapshots. The actual continuous-rotation MG90S variants and camera must be measured before the power design is released as a tested build.

## Recommendation

Use a removable **Tattu 450 mAh 2S 75C long battery**, part **TA-75C-450-2S1P-L-XT30** / SKU **TAA4502S75X3L**, and a **Pololu D30V30MALCMA, item 4872**, adjusted to **5.00 V**. Charge the removed pack with a **SkyRC B6neo SK-100198** balance charger. The servo already contains its motor driver: no external H-bridge or ESC is needed for a continuous-rotation servo. A voltage regulator is needed; a custom PCB is not needed for this prototype.

The battery manufacturer lists **61 × 16 × 15 mm**, **28.4 g**, **7.4 V nominal**, an XT30 discharge connector and a three-contact JST-XH balance connector. Its page showed **$7.22** and stock **>100**. The pack is rated well above the few amperes expected here; the connector/wiring/regulator remain separate limits. This is an ordinary 4.2 V/cell LiPo, not LiHV. [Tattu product page](https://www.genstattu.com/tattu-450mah-7-4v-75c-2s1p-lipo-battery-pack-with-xt30-plug-long-size-for-h-frame.html)

The regulator measures **15.2 × 25.4 × 9.0 mm**, has adjustable output and adjustable undervoltage cutoff, and includes reverse-input, overcurrent and thermal protections. It was listed **$39.95**, rationed/backorders allowed; immediate dispatch is not confirmed. Its 3.4 A headline rating is not a universal limit. The manufacturer's 5 V curve is approximately **3.7–3.9 A at 6–8.4 V input**, in open still air at room temperature. Enclosure performance requires testing. [Pololu 4872](https://www.pololu.com/product/4872), [current curve](https://a.pololu-files.com/picture/0J12632.600.png), [dimension drawing](https://www.pololu.com/file/0J2035/d30v30max-fine-adjust-step-down-voltage-regulator-dimensions.pdf)

CAD battery cavity target: **66 × 20 × 19 mm**, plus a distinct cable/connector pocket; this clearance is a design allowance, not a manufacturer tolerance guarantee. Use a strap and soft padding, never screws or a tight interference fit against a pouch cell. Reserve **18 × 28 × 12 mm** for the regulator with underside clearance and airflow. The board has components on both faces. These are nominal component/envelope models, not verified replicas of purchased specimens.

## What the power controller does

| Function | Prototype implementation |
|---|---|
| Motor direction/speed | Electronics inside each continuous-rotation servo; ESP32 sends its control pulse |
| Battery voltage conversion | Pololu 4872 converts 2S voltage to a shared 5 V supply |
| Hard OFF | Unplug the accessible XT30 connector |
| Optional standby | Small switch between regulator EN and GND; this does not physically disconnect the battery |
| Charging/balancing | External SkyRC balance charger, battery removed from car |
| Hardware low-pack cutoff | Pololu cutoff adjusted and verified at 6.2 V, as a last-resort backup |
| Normal low-battery operation | Stop at about 7.0 V pack / 3.5 V per cell; monitor during prototype use |
| Per-cell protection | Not built into the selected RC pack or regulator; see limitations below |

Avoid an ordinary tiny slide switch in the main current path unless its **DC** current rating supports the measured load. An optional EN switch handles only a signal. Always unplug after use, including after a low-voltage shutdown.

## Wiring

```text
2S battery XT30 + --> inline fuse --> regulator VIN
2S battery XT30 - ------------------> regulator GND
                                      |
                  regulator VOUT = 5.00 V
                      +---------------+---------------+
                      |               |               |
                left servo +    right servo +   ESP32-S2 Mini 5V/VBUS
                      |               |               |
                      +--- separate camera/VTX branch--+

All return wires meet at regulator GND / a soldered distribution point.
ESP32 signal pins --> servo signal wires, with shared ground.
Battery balance connector --> charger ONLY during charging / cell measurement.
```

Do not route servo supply current through the ESP32 board, USB connector, GPIO pins, 3.3 V regulator, or a solderless breadboard. Use a short soldered star harness, **22 AWG or thicker** stranded supply/return wires, insulated joints, and strain relief. Use a fuse close to the battery connector; **4 A nominal** is a starting design choice to validate against inrush and the actual wire/fuse time-current ratings, not servo overload protection. Choose a DC-rated fuse with interrupt rating suitable for a LiPo source. Do not alter the battery's original leads.

Add **1000 µF / 10 V** across 5 V/GND near the servo power split, and **100 µF / 10 V plus 100 nF** at the controller/camera branch. These are starting values to validate, not a cure for an undersized converter. A concrete bulk capacitor is Panasonic **EEUFR1A102**, **10 mm diameter × 16 mm body**, 5 mm lead pitch; allow lead bend/insulation clearance. [Panasonic component page](https://industrial.panasonic.com/ww/products/pt/aluminum-cap-lead/models/EEUFR1A102)

Give the camera its own supply/ground pair back to the star point. Add a suitably rated LC filter only if the powered video test shows motor noise; an arbitrary filter can create voltage drop or resonance. Keep camera RF antenna and ESP32 antenna away from motor leads and the switching regulator.

The genuine LOLIN S2 Mini schematic connects its USB VBUS and board power circuitry without a complete battery charger or a dual-source power mux. **Disconnect the car's 5 V feed to the S2 Mini before connecting powered USB for flashing**, and leave servo power off during that work. Verify clone boards separately. A battery attached to VIN must never touch the S2 Mini's 5 V or 3.3 V pins directly. [LOLIN schematic](https://www.wemos.cc/en/latest/_static/files/sch_s2_mini_v1.0.0.pdf)

## Current budget and runtime

These are engineering allowances, **not measured MG90S specifications**. Continuous-rotation servos sold under this name differ substantially. Do not borrow an unrelated positional MG90S stall-current number as a guarantee.

| 5 V load | Running assumption | Short peak allowance |
|---|---:|---:|
| Two servos | 2 × 0.25 A = 0.50 A | 2 × 1.20 A = 2.40 A |
| S2 Mini, Wi-Fi active | 0.15 A | 0.40 A |
| Tiny 25 mW camera + VTX | 0.25 A | 0.35 A |
| **Total** | **0.90 A** | **3.15 A** |

At 3.15 A output, 5 V output, 6.2 V input and assumed 90% conversion efficiency, battery current is approximately **2.82 A**. A pack's high C rating does not make this test unnecessary. If the actual camera uses more power, update this table. Never substitute RF transmission power (25 mW) for its electrical input power.

Battery energy is 7.4 V × 0.45 Ah = **3.33 Wh**. With an assumed usable fraction of 80% and 90% conversion efficiency, load energy is about **2.40 Wh**. That predicts **32 minutes at 0.90 A average** or **19 minutes at 1.50 A average**, both on the 5 V rail. Early cutoff, friction, carpet, turning scrub, pack condition, radio duty cycle and camera power can shorten this. Treat **roughly 15–30 minutes** as a planning range, not a tested promise.

## Low-voltage setup and its limits

The cutoff is **pack-level**, not a 2S battery-management system. An unbalanced pack can have one low cell even when its total looks acceptable. Balance charge every time, measure both cells before use, stop if cells diverge, and remove the battery when finished. Normal operating target is **at least 3.5 V/cell under load**. The manufacturer advises 3.5 V/cell for Tattu UAV operation and specifies never going below 3.0 V/cell under load. [Tattu battery guidance](https://www.genstattu.com/bw/)

The regulator cutoff has unusually large restart hysteresis: its EN threshold is typically 0.85 V with approximately 0.20 V hysteresis. Restart voltage is therefore approximately `cutoff × (1 + 0.20 / EN_threshold)`. A 6.2 V cutoff typically restarts around 7.66 V, while threshold variation can put it near 8.11 V. **A 7.0 V hardware cutoff can prevent startup even on a fully charged 8.4 V pack.** This is why 6.2 V is only the backup, with earlier normal stopping. Actual thresholds must be measured. [Pololu cutoff procedure](https://www.pololu.com/product/4872)

With loads disconnected, use an adjustable supply and a multimeter to set VOUT to 5.00 V, set/verify falling cutoff at 6.2 V, and verify restart at no more than the fully charged pack voltage. Pololu also gives a multimeter-only threshold calibration method when a variable supply is unavailable; use its measured EN threshold rather than assuming 0.85 V. The original B6neo's digital-power mode can serve as the variable supply for this low-load calibration when used with the proper output cable. Recheck VOUT after adjustment and before connecting any electronics.

The design now includes a GPIO7-controlled **BS250P / 2N3904 high-side sensing switch**, a 100 kΩ / 33 kΩ divider, and a 100 nF filter into GPIO3. See the exact net table and commissioning sequence in [wiring.md](../electronics/wiring.md). The pull-up/pull-down network defaults sensing OFF when MCU power disappears, avoiding a sustained battery-fed ADC path; verify actual power-off behavior. Firmware enables sensing, waits at least 20 ms, reads/calibrates pack voltage and disables sensing again. The normal stop is 7.0 V; it still cannot identify an individual weak cell. Measure both cells during supervised prototype operation and stop if cells diverge. For unattended discharge protection, add a properly rated per-cell protector or a purpose-designed power board.

## Charging

Choose the **original SkyRC B6neo SK-100198** or an already-owned equivalent that explicitly supports 2S LiPo balance charging at **0.4 A or less**. B6neo supports 1–6S lithium packs, balance/storage modes, USB-C PD power and 0.2–10 A charge current. It is an external bench tool, **70 × 50 × 31 mm**, not part of the car. Connect its main output through a polarity-checked XT60-to-XT30 charging adapter and also connect the three-pin balance lead using the charger's documented 2S alignment. Supply it with a compatible USB-C PD adapter/cable; a plain 5 V USB supply is not sufficient for the original model's PD input specification. [SkyRC specifications](https://www.skyrc.com/b6neo-series), [original B6neo manual](https://www.skyrc.com/download/100198%20B6neo%20Instruction%20Manual%20V1.0_231206.pdf)

Set **LiPo / 2S / balance charge / 4.20 V per cell / 0.4 A**. 0.4 A is below 1C for a 450 mAh pack. Remove the pack from the printed car and supervise charging on a nonflammable surface. Use the charger's storage mode for storage; do not charge a swollen, damaged or unbalanced pack. No onboard charger, TP4056 board or charge-and-drive feature is needed. A TP4056 is a 1S charger and cannot charge this 2S battery.

## Why not a 1S build?

| Choice | Assessment |
|---|---|
| 1S directly into servo + board | 3.0–4.2 V is below the intended 5 V rail; inconsistent servo behavior and regulator dropout are likely. Not the baseline. |
| 1S high-discharge pack + proper boost | Feasible, potentially flatter, but at 5 V/3.15 A, 3.3 V battery and 85% efficiency it needs **5.6 A battery current**. Requires a converter rated at low input voltage plus appropriate connector, cell protection and charger. |
| 1S generic protected 1200 mAh hobby cell + small USB boost | Not an acceptable automatic substitution. The Adafruit 1200 mAh example has 2 A-rated cables, below this design's possible boost input demand. [Example battery](https://www.adafruit.com/product/258) |
| **2S high-discharge pack + 5 V buck** | **Selected**: less input current, narrow battery shape, hardware cutoff available, straightforward external balance charging. |

A cheaper fixed 5 V buck may work electrically but does not automatically provide appropriate low-battery cutoff. The compact Pololu S9V11 cutoff boards have only up to 1.5 A output in buck operation and a 700 mA startup limit, so they are not a substitute for the selected power stage. [Pololu S9V11 example](https://www.pololu.com/product/2870)

## Bench acceptance before printing the final chassis

1. Confirm both servos rotate continuously and identify neutral pulses with wheels lifted; reject a positional or multi-turn positional substitute.
2. Verify polarity, 5.00 V output, hardware cutoff and restart before connecting the electronics.
3. Measure no-load, driving and brief startup/reversal currents; do not hold tiny servos stalled. Test full battery and a 6.5–7.0 V supply. Use a current-limited supply first.
4. Exercise both servos and the camera while transmitting Wi-Fi. Check for ESP32 resets, video breakup and voltage dips at the servo and MCU connectors. A scope is preferable for short dips that a multimeter can miss.
5. Run a thermal test in the proposed enclosure at realistic worst continuous load. Keep air around the regulator. If the rail droops, resets or overheats, change the power design before road use.
6. Record per-cell battery voltage and measured runtime; revise the estimated table using those measurements.

A soldered harness and off-the-shelf modules suit a basic soldering kit. A custom PCB becomes worthwhile only after fit/current testing, or if integrated per-cell cutoff, gated sensing, a real power button, USB power-source isolation or compact onboard balancing is required. It is not needed to get this first car rolling.

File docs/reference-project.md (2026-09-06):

# What the reference project actually contains

Inspected 2026-09-05 (local time). Upstream commit: `067cbcc8ea202b5367174b04307b865cb0d397f4`.

The [Pro Know repository](https://github.com/proknowdiy/micro_rc_fpv_car_esp-now) inspired this project. Its README links [Making a Micro FPV RC Car - ESP NOW](https://www.youtube.com/watch?v=aJbycyJAl0k). Upstream has an MIT license. This repository independently models and documents a different chassis and electronics; no upstream CAD or firmware has been copied.

## Camera identified from the creator's links

The video's own description names DFRobot 2.5 g continuous servos and a 3.7 V, 200 mAh LiPo. Its camera link, `https://bit.ly/3z0JrOv`, resolves to [IDC-681H 25 mW 40CH VTX 600TVL M7 FPV camera](https://robu.in/product/idc-681h-25mw-40ch-vtx-600tvl-m7-fpv-camera/). Its receiver link, `https://bit.ly/3yJWRyk`, resolves to [EWRF 5.8 GHz UVC OTG Android AV phone receiver](https://robu.in/product/ewrf-5-8g-uvc-otg-android-av-phone-receiver/). These are evidence of the creator's product choices, not proof that every currently sold revision is identical.

This is an analog camera with an integrated 5.8 GHz video transmitter. Its video path is separate from the ESP32 control link. A compatible analog receiver/display is required; a phone needs compatible UVC/OTG hardware and software. It does not stream video through ESP-NOW.

## Important disagreement between the uploaded files

The [receiver sketch](https://github.com/proknowdiy/micro_rc_fpv_car_esp-now/blob/067cbcc8ea202b5367174b04307b865cb0d397f4/Code/Receiver_with_elevon_mix/Receiver_with_elevon_mix.ino) controls two servos on GPIO27/26 with 1000–2000 microsecond pulses and a one-second loss-of-signal timeout. Those pin assignments are not portable to the S2 mini.

However, the [receiver BOM](https://github.com/proknowdiy/micro_rc_fpv_car_esp-now/blob/067cbcc8ea202b5367174b04307b865cb0d397f4/PCB%20Files/Receiver/BOM_ESP-WROOM-32-ESP-NOW-RECEIVER_2025-07-0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) specifies an MX1508 motor driver, ESP32-WROOM module, AMS1117-3.3 regulator, capacitors, resistors and a BZV55C5V6 zener. The [receiver schematic](https://github.com/proknowdiy/micro_rc_fpv_car_esp-now/blob/067cbcc8ea202b5367174b04307b865cb0d397f4/Diagram/Schematic_ESP-WROOM-32-ESP-NOW-RECEIVER_PCB.pdf) has bare motor outputs, a misleading “L293D” section title, and a TC1508A alternative note. Its power circuit contains an AMS1117 and a resistor/zener branch, not a boost converter. The resistor/zener branch labeled +5V cannot supply the proposed servos.

The published schematic/BOM show no charger, battery protection, or undervoltage cutoff. They are not a validated, directly reusable power design for this car. The continuous servos contain their own motor drive electronics; an external MX1508 is unnecessary. Use the independent power design in [power.md](power.md).

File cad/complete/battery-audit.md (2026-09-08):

# Independent battery dimension audit

Checked **2026-09-08**, against the saved `complete-spy-car.blend` at revision `49a3692`. This audit measured the saved geometry independently; it did not change or resave the Blender file. The separately modified `cad/rolling/rolling-chassis.blend` was not touched.

## Saved geometry

Both scenes were activated and their dependency graphs updated before reading world transforms. Measurements include all 13 `Battery •` objects (wrap, illustrative cells, folds and label), and exclude foam, wires and connectors.

| Scene | World X × Y × Z extent | World minimum | World maximum |
| --- | --- | --- | --- |
| `01 ASSEMBLED` | 48.000000 × 17.000004 × 12.000000 mm | −24, −11.000002, 28 | 24, 6.000002, 40 |
| `02 EXPLODED` | 48.000000 × 17.000004 × 12.000008 mm | −54, −11.000002, 79.999992 | −6, 6.000002, 92 |

The small deviations are floating-point precision. The wrap has unit object scale, no parent, local dimensions **17 × 48 × 11.96 mm**, and a −90° rotation about Z. Its world dimensions are **48 × 17 × 11.96 mm**; the label brings the finished pack to 12 mm. Exploding the assembly translates the battery without stretching it. No hidden scaling or width/height interchange was found.

## Live Blender check

The parent agent separately queried the user's currently open `01 ASSEMBLED` scene through Blender's Python console: the wrap reports local dimensions **17 × 48 × 11.96 mm**, scale **1, 1, 1**, and transformed world dimensions **48 × 17 × 11.96 mm**. The file already includes `03 BATTERY DIMENSIONS`, so this was the updated model rather than an older open copy. No geometry was changed or saved; the existing unsaved state was preserved and the 3D view restored.

## Manufacturer sources conflict

| Source for the selected 300 mAh 2S 75C XT30, SKU 10188 | Dimensions | Weight |
| --- | --- | --- |
| [Lumenier product listing](https://www.lumenier.com/products/lumenier-300mah-2s-75c-lipo-battery-xt-30) | Explicitly **length 48, width 17, height 12 mm** | 18 g |
| [MSDS linked from that listing, page 2](https://cdn.shopify.com/s/files/1/0698/9525/8342/files/66_10188_Lumenier_300mAh_2s_75c_Lipo_Battery_XT-30.pdf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) | **13 × 16 × 45 mm**, with no axis labels | About 25 g |

The MSDS names the exact 2S 300 mAh XT30 product and specifies 7.4 V / 2.22 Wh. It was issued December 25, 2024, effective January 1, 2025. The discrepancy was checked in the rendered table, not inferred from text extraction. Neither source explains whether the difference reflects a sample revision, measurement convention or documentation error.

The listing's [generic dimension icon](https://cdn-v2.getfpv.com/media/wysiwyg/product-detail-images/height-length-width.png) uses height vertically and width horizontally. It provides no evidence that 17 and 12 should be exchanged. The [manufacturer photograph](https://cdn.shopify.com/s/files/1/0698/9525/8342/files/lumenier-300mah-2s-xt30-main_1.jpg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) visibly shows a 2 CELL 7.4 V label and XT30 connector; no different-SKU mismatch was established.

## What the visual mismatch means

The model matches one published envelope; that does **not** establish an exact physical replica. The photograph shows tapered, folded shrink-wrap, while the model remains a mostly constant-height rounded cuboid. Correct maximum bounds alone cannot verify that silhouette. Camera angle, foreshortening and partially obscured lower edges also affect apparent thickness, but are not proof that the user's concern is mistaken.

The assembly also places the XT30 pair and balance connector above the pack; the product photo places its loose connectors beside it. Those are additional objects, not extra battery thickness, but they make the installed package look taller. The observed user viewport looks toward a short end and foreshortens the long dimension. Neither observation resolves the physical silhouette uncertainty.

No source found justifies flattening the model to a different thickness. The MSDS does not establish a thinner pack either. Keep 48 × 17 × 12 mm explicitly provisional until the actual selected pack is measured: maximum length/width/height including wrap, thickness through the central body versus folded ends, and lead exits. Those measurements should control the final battery model and retention fit.

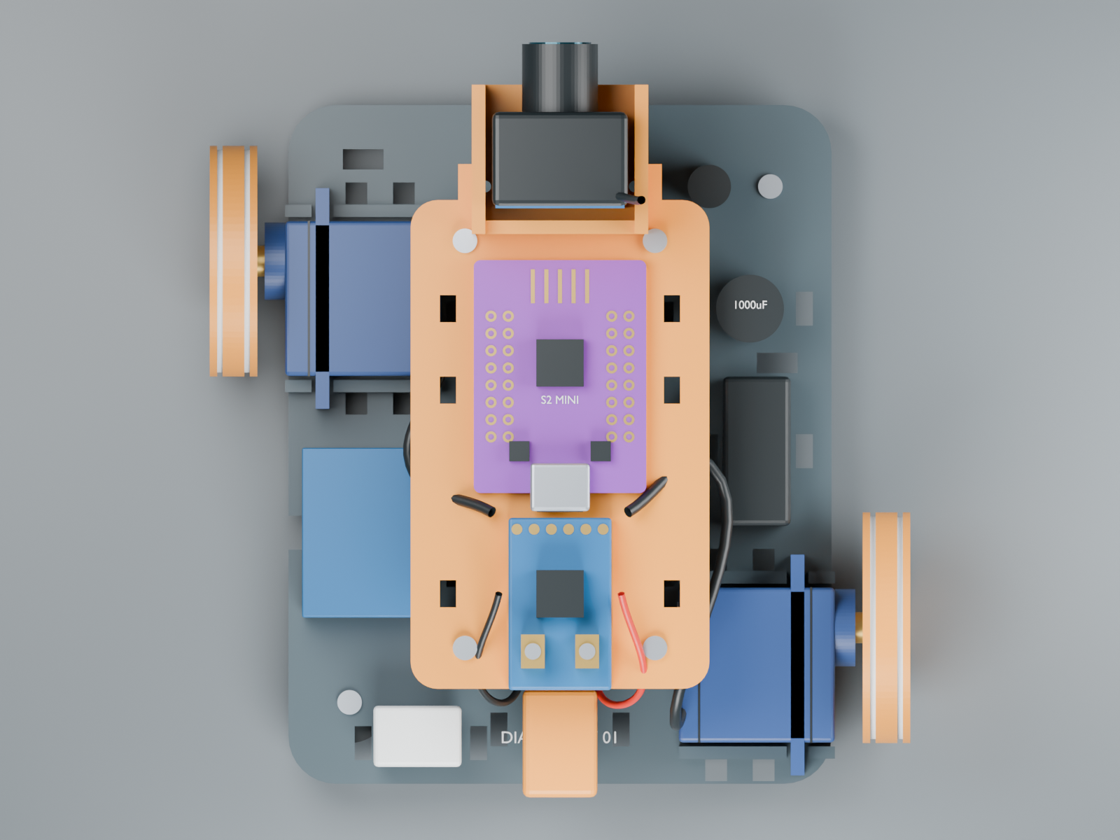
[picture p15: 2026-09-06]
images/top.png

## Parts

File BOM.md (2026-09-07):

# Historical bill of materials

> **Historical BOM — do not order this list for the current build.** This table records the original camera-equipped Tattu/Pololu proposal and is retained for design history. The current camera-free build uses the owned LM2596-style buck and a Lumenier 300 mAh 2S XT30 pack. Use the [current camera-free BOM](electronics/camera-free-bom.csv), [current wiring](electronics/wiring.md), and [picture wiring guide](output/pdf/spy-car-wiring-guide.pdf). The old camera, Pololu cutoff/enable switch, capacitor choices and subtotal below are not the current selection.

Research snapshot: 2026-09-05. Quantities cover one car plus one radio controller. Owned parts are marked. Prices exclude shipping/tax and are not a complete project total. Generic hardware dimensions must be checked before buying.

| Ref | Qty | Item / part | Status | Price USD | Source |
|---|---:|---|---|---:|---|
| BAT1 | 1 | Tattu 450mAh 2S 75C long LiPo — TA-75C-450-2S1P-L-XT30 | yes | 7.22 | [source](https://www.genstattu.com/tattu-450mah-7-4v-75c-2s1p-lipo-battery-pack-with-xt30-plug-long-size-for-h-frame.html) |
| U_PWR | 1 | Adjustable buck regulator with low-voltage cutoff — Pololu D30V30MALCMA item4872 | yes | 39.95 | [source](https://www.pololu.com/product/4872) |
| C_BULK | 1 | 1000uF 10V low-ESR radial electrolytic — Panasonic EEUFR1A102 | yes | — | [source](https://industrial.panasonic.com/ww/products/pt/aluminum-cap-lead/models/EEUFR1A102) |
| C_LOGIC | 1 | 100uF 10V radial electrolytic — Select stocked equivalent | yes | — | Select locally |
| C_BYPASS | 1 | 100nF ceramic 16V or higher — Select stocked through-hole equivalent | yes | — | Select locally |
| J_BAT | 1 | XT30 mating connector with 22AWG or thicker pigtail — AMASS-compatible keyed XT30 mate | yes | — | Select locally |
| F_IN | 1 | Inline DC fuse nominal4A plus insulated holder or leaded assembly — Select DC-rated part after inrush test | yes | — | Select locally |
| HARNESS | 1 | Stranded22AWG supply wire and soldered distribution harness — Hookup wire / heatshrink / strain relief | yes | — | Select locally |
| SW_EN | 1 | Small SPST switch across regulator EN-GND — Generic low-current signal switch | optional | — | Select locally |
| CHG1 | 1 | 2S-capable balance charger with low-current setting — SkyRC B6neo SK-100198 | yes_unless_owned | — | [source](https://www.skyrc.com/b6neo-series) |
| CHG_ADAPTER | 1 | XT60 charger-output to XT30 battery adapter — Polarity-checked mating lead | yes_unless_owned | — | Select locally |
| CHG_SUPPLY | 1 | Compatible USB-C PD supply and cable — 12-20V PD support for original B6neo | yes_unless_owned | — | [source](https://www.skyrc.com/b6neo-series) |
| DMM | 1 | Digital multimeter with DC voltage and current measurement — User-owned or suitable meter | yes_unless_owned | — | Select locally |
| LIPO_BAG | 1 | LiPo charging and storage bag — Select reputable bag | recommended | — | Select locally |
| QP_SENSE | 1 | Through-hole P-channel MOSFET battery-sense switch — Diodes BS250P | yes | 1.75 | [source](https://www.diodes.com/datasheet/download/BS250P.pdf) |
| QN_SENSE | 1 | Through-hole NPN battery-sense gate driver — onsemi 2N3904BU | yes | — | [source](https://www.onsemi.com/download/data-sheet/pdf/2n3904-d.pdf) |
| R_SENSE_100K | 3 | 100k ohm1percent axial resistor — Stocked metal-film equivalent | yes | — | Select locally |
| R_SENSE_33K | 1 | 33k ohm1percent axial resistor — Stocked metal-film equivalent | yes | — | Select locally |
| R_SENSE_10K | 2 | 10k ohm axial resistor — Stocked metal-film equivalent | yes | — | Select locally |
| C_SENSE | 1 | 100nF ceramic16V or higher — Stocked through-hole equivalent | yes | — | Select locally |
| PROTO_SENSE | 1 | Insulated perfboard for switched sensing and divider — Small cuttable perfboard | yes | — | Select locally |
| M_FL_RR | 2 | Owned MG90S-style 360 degree continuous servos — Exact owned variant TBD | owned | — | [source](https://towerpro.com.tw/product/mg90s-3/) |
| MCU_RX | 1 | LOLIN WEMOS S2 mini — ESP32-S2FN4R2 S2 mini V1.0.0 | owned | — | [source](https://www.wemos.cc/en/latest/s2/s2_mini.html) |
| CAM1 | 1 | Creator-linked analog FPV AIO camera — IDC-681H 25 mW 40CH 600TVL M7 | yes_for_FPV | — | [source](https://robu.in/product/idc-681h-25mw-40ch-vtx-600tvl-m7-fpv-camera/) |
| V_RX | 1 | Analog 5.8 GHz video receiver — EWRF 5.8 GHz UVC OTG Android AV receiver | yes_for_FPV | — | [source](https://robu.in/product/ewrf-5-8g-uvc-otg-android-av-phone-receiver/) |
| MCU_TX | 1 | Second ESP32 development board — Classic ESP32 DevKit assumed | owned_if_available | — | [source](https://docs.espressif.com/projects/arduino-esp32/en/latest/) |
| JOY1 | 1 | Two-axis spring-centered analog joystick — 3.3 V potentiometer joystick; exact module TBD | yes | — | Select locally |
| DEADMAN | 1 | Normally open momentary pushbutton — SPST button to GND | yes | — | Select locally |
| TX_POWER | 1 | USB power bank and board-compatible cable — User-owned USB source | yes_unless_owned | — | Select locally |
| SERVO_HORNS | 2 | Factory servo horns and original shaft screws — Supplied with owned servos | owned | — | Select locally |
| HORN_FIX | 4 | Wheel-to-horn fasteners — Choose matching factory horn screws or M1.6/M2 bolts + nuts | yes | — | Select locally |
| M2_DECK | 4 | Deck mount screws — 2 mm x 6 pan head plastic-tapping screws or coupon-verified M2 | yes | — | Select locally |
| M2_SKID | 2 | Skid mount screws — 2 mm x 6 pan head plastic-tapping screws or coupon-verified M2 | yes | — | Select locally |
| M2_CAM | 2 | Camera cradle screws — 2 mm x 5 pan head plastic-tapping screws or coupon-verified M2 | yes | — | Select locally |
| TIES | 12 | Nylon cable ties — Approximately 2.5 mm wide; 100 mm long | yes | — | Select locally |
| FOAM | 1 | Thin nonconductive foam and insulation — 0.5–1 mm foam plus polyester/Kapton insulation | yes | — | Select locally |
| VELCRO | 1 | Camera retention strap — Thin strap through 2.5 mm side windows | yes | — | Select locally |
| PTFE | 1 | Low-friction skid contact tape — Thin PTFE tape | recommended | — | Select locally |
| PRINT | 1 | Eight supplied STLs — PETG or PLA; 0.4 mm nozzle | yes | — | Select locally |
| CALIPER | 1 | Digital caliper — 0.1 mm or better useful resolution | yes_unless_owned | — | Select locally |

The verified-price subtotal for the battery, buck regulator and BS250P is **$48.92**. Camera, charger, viewing hardware, connectors and consumables are additional. Check current stock: the Pololu regulator was rationed/backordered at research time.

See [BOM.csv](BOM.csv) for dimensions and per-row notes, [power design](docs/power.md), [wiring](electronics/wiring.md), and [assembly](docs/assembly.md).

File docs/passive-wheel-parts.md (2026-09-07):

# Passive wheel parts — v0.4

This **mechanical stage** uses the two owned continuous-rotation MG90S servos and two purchased bearings. Electronics are outside this list. The chassis is one printed part with integrated stationary axles, inner-ring abutments and servo-ear clips. Wheels are separate printed moving parts. The interface to the servos’ original supplied horns remains future work.

| Part | Quantity | Price / availability | Source |
|---|---:|---|---|
| Owned continuous-rotation MG90S servos | 2 | Already owned | Measure the actual cases, mounting ears and supplied horns |
| Avid MR83ZZ, steel/chrome bearing with metal shields, **3 mm ID × 8 mm OD × 3 mm wide** | 2 | **$1.00 each**, last checked **2026-09-07**; listing then showed **73 in stock** | [Buy from Avid](https://www.avidrc.com/product/p/227/3x8x3-Metal) · [product photograph](https://www.avidrc.com/shop/images/products/large_227_5602db2f85619.jpg) |

**Additional purchased mechanical parts: two bearings, $2.00 total**, excluding shipping, taxes and printing material. There are no purchased axles, caps, spacers, nuts or screws in v0.4. Prices and availability can change.

## Bearing and wheel fit

Each passive wheel carries one bearing. Its **outer ring fits into the wheel’s nominal 8.0 mm pocket** and rotates with the wheel. Its **inner ring fits over the chassis’s nominal 3.0 mm stationary printed journal**. These are intended friction fits; equal nominal CAD dimensions do **not** establish a reliable press fit on an FDM printer.

A **4.0 mm OD abutment**, integrated into the chassis, contacts the inner ring only. The wheel and bearing shield must clear this stationary feature. The [KMT manufacturer catalog](https://www.e-kmt.com/wp-content/themes/dc_e-kmt/img/download/dl03.pdf), miniature-bearing table on printed pages 5–6, gives **4.0 mm maximum shaft-abutment diameter for MR83ZZ**. This is supporting reference geometry, **not an Avid-specific abutment drawing**: inspect the purchased bearing’s exposed inner-ring contact land and confirm the printed abutment clears its shield.

There is **no end clip**. Axial retention depends entirely on friction at both the bearing-to-wheel and bearing-to-journal interfaces. Pull-off resistance, PETG creep, journal durability and the physical fits have not been validated. The nominal model must not be treated as a proven retained wheel assembly.

## Fit coupon and physical checks

Before printing the full chassis, print a coupon with **7.9 / 8.0 / 8.1 mm bearing holes** and **2.9 / 3.0 / 3.1 mm journal pegs**. Reproduce the final parts’ **horizontal bore/journal orientation, supports, material and slicer settings**; a vertical coupon does not characterize the horizontal features. Remove support material carefully and measure the resulting features. If none fits, adjust the coupon sizes before changing the complete model.

Choose fits that retain both rings without cracking the wheel, damaging the printed journal or causing bearing drag. When seating a bearing in the wheel, apply force to its outer ring; when seating it on the journal, support its inner ring. Do not force assembly loads through the balls or shields.

With the wheel installed, verify free rotation, shield clearance, low wobble and secure axial retention. Pull the wheel outward by hand to test both friction interfaces and check again after repeated rotation, a short low-speed floor test and time under load. Any loosening, creep, binding or easy pull-off means the fit needs revision before use. Check the integrated servo-ear clips against the actual servos as well; their retention is also unverified until physically tested.

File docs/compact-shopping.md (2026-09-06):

# Camera-free compact build: shopping shortlist

Researched 2026-09-06. These are candidates for the next smaller design; the existing CAD, BOM and firmware have not been revised to implement this layout. Dimensions below are supplier envelopes, not measured replicas. Prices exclude tax and shipping.

## Preferred battery

[Lumenier 300mAh 2S 75C LiPo, XT30, SKU 10188](https://www.racedayquads.com/products/lumenier-300mah-2s-75c-lipo-battery-xt-30) — $13.49; retailer product data showed available at research time. **48 × 17 × 12 mm, 18 g**, nominal 7.4 V, fully charged 8.4 V. Allow extra room for cables, connector bends, padding and pack tolerances.

[Manufacturer specifications](https://www.lumenier.com/products/lumenier-300mah-2s-75c-lipo-battery-xt-30).

Lumenier 300mAh 2S XT30 battery; retailer photo

This is 13 mm shorter than the original 61 mm pack, with two thirds of its nominal capacity. Real runtime depends on servo load and must be measured. Retain an external 2S balance charger; select a charge current permitted by the pack instructions (0.3 A corresponds to 1C). This RC pack does not supply a complete battery-management system.

## Preferred regulator candidate

[Pololu S13V30F5, item 4082](https://www.pololu.com/product/4082) — $17.95; backorders allowed, dispatch availability not confirmed. **22.9 × 22.9 × 9.7 mm**, fixed 5 V, buck-boost topology, 2.8–22 V input. Solder wires directly to avoid the height of the included terminal blocks.

Pololu S13V30F5 regulator; manufacturer photo

The manufacturer's 3 A class rating varies with input voltage and cooling. Our provisional 2.8 A peak allowance for two servos plus the ESP32 is not a measurement: test simultaneous startup, reversal, brief stall and enclosure temperatures before approving this board for the build.

The default undervoltage lockout is not an appropriate 2S LiPo discharge cutoff. Its EN input supports an external resistor divider for a higher cutoff, accounting for the onboard 475 kΩ pullup. A proposed calibrated 7.0 V falling threshold requires physical validation: the documented maximum hysteresis could require about 8.33 V to restart. This leaves little margin below an 8.4 V full pack. Verify both thresholds, startup under load and battery rebound behavior before relying on it. This is pack-level cutoff, not individual-cell protection; unplug the battery after use.

## Smaller alternative, currently unavailable

[BETAFPV 300mAh 2S 45C XT30, two pack](https://betafpv.com/products/300mah-2s-lipo-battery-2pcs) — $12.99/two listed, **sold out** at research time. **45 × 17 × 12 mm, 18.4 g** per pack. Only 3 mm shorter than the available Lumenier option.

## Build implications

Battery plus regulator total: **$31.44**, excluding small parts and charging equipment. Reuse the owned S2 Mini and two continuous-rotation servos. No motor driver or custom PCB is inherently required: the servos contain their own drivers. Still budget for a mating XT30 pigtail, switch, cutoff resistors, decoupling capacitor, wire and insulation. The exact cutoff circuit and compact mechanical placement remain to be validated.

Suggested placement: two staggered servos below, battery beside the S2 Mini and regulator on an upper deck. The discussed roughly 50 × 70 mm vehicle footprint remains an estimate pending CAD fit checks. Product photos above are externally hosted, credited references and are not covered by this repository's MIT license.

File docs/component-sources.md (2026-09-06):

# Component geometry and evidence

Research date: 2026-09-05 (America/Los_Angeles). Dimensions are millimetres. A manufacturer outline is not an exact replica of a particular clone or purchased revision. Measure the owned parts before a final fit print.

## LOLIN S2 mini

[WEMOS official board documentation](https://docs.wemos.cc/en/latest/s2/s2_mini.html) specifies a **34.3 × 25.4 mm** board, 2.4 g, ESP32-S2FN4R2, 4 MB flash and 2 MB PSRAM. The [official V1.0.0 mechanical PDF](https://docs.wemos.cc/en/latest/_static/files/dim_s2_mini_v1.0.0.pdf) dimensionally confirms that outline; it also shows two 2 mm holes at 20.4 mm transverse spacing, with the left hole 2.5 mm from the edge. It does not dimension the holes' longitudinal position, PCB thickness, USB shell or component heights. Do not infer exact mounting geometry from a different “ESP32 mini” board name. Board-edge retention avoids relying on incompletely dimensioned holes.

The [official V1.0.0 schematic](https://docs.wemos.cc/en/latest/_static/files/sch_s2_mini_v1.0.0.pdf) shows ME6211C33 onboard 3.3 V regulation and direct VBUS connection to the 5 V header. It does not contain a LiPo charger, boost converter or servo power stage. GPIO runs at 3.3 V. Supply regulated 5 V at the board's 5 V/VBUS pin and common ground; disconnect external 5 V before plugging in ordinary USB power unless an explicit power-isolation arrangement has been installed.

**Geometry status:** board outline is manufacturer specified. Decorative packages, solder pads, connector dimensions and clearance volumes are modeling assumptions unless separately measured. Do not label the complete board model “exact.”

## IDC-681H camera from the video

Identification comes from the [creator's video description](https://www.youtube.com/watch?v=aJbycyJAl0k) and its [resolved camera listing](https://robu.in/product/idc-681h-25mw-40ch-vtx-600tvl-m7-fpv-camera/). The linked listing identifies the IDC-681H 25 mW 40-channel 600TVL M7 unit. The original retailer currently serves incomplete product content to research tools. No authoritative dimensional drawing or manufacturer electrical datasheet was located.

**Geometry status:** reserve an adjustable camera bay and use an explicitly provisional envelope. The CAD camera is not an exact replica. Confirm total lens-to-PCB depth, board width/height, mounting features, rear connector/wire bend space, antenna exit and button access after sourcing the unit. Do not print a tight friction socket from the provisional model.

**Electrical status:** the design budget provision of 0.25 A working / 0.35 A peak at regulated 5 V is a planning assumption. Verify the delivered module's permitted supply and measure actual current before connection. Never connect this provisioned camera directly to the 2S pack. Do not interpret the 25 mW radio output rating as electrical input consumption.

A manufacturer-documented fallback is the [Eachine TX06](https://www.eachine.com/Eachine-TX06-700TVL-FOV-130-Degree-5_8Ghz-40CH-Smart-Audio-Mini-FPV-Camera-AIO-Transmitter-For-RC-Dr-p-1418.html): 25 mW, 700TVL, 3.3–5.5 V input. Its official page lists both 280 mA working current and 40 mA at 3.7 V, so use the higher figure as the preliminary budget and verify the delivered unit. This fallback is a different camera and requires its own fit check; it is not evidence for IDC-681H geometry.

## MG90S-style continuous servos

The two owned units are the controlling mechanical reference. “MG90S” alone does not establish a continuous-rotation variant, spline count, body/ear dimensions, neutral pulse, stall current or clone manufacturer. Confirm continuous rotation on the bench; obtain dimensions from calipers and retain the supplied horn/center screw interface. Treat the visual servo model as a dimensional proxy until the recorded dimensions match the physical units. Exact manufacturer claims for a positional MG90S must not be applied to an unidentified 360-degree version.

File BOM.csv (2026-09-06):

ref | quantity | category | item | manufacturer_part | nominal_dimensions_mm | unit_price_usd | price_status | required | url | notes
BAT1 | 1 | on_car | Tattu 450mAh 2S 75C long LiPo | TA-75C-450-2S1P-L-XT30 | 61 x 16 x 15 | 7.22 | Manufacturer page checked 2026-09-05; stock >100 | yes | https://www.genstattu.com/tattu-450mah-7-4v-75c-2s1p-lipo-battery-pack-with-xt30-plug-long-size-for-h-frame.html | 7.4V nominal / 8.4V full; XT30 main and JST-XH 3-pin balance; nominal28.4g; reserve66x20x19 plus wires; no per-cell protector assumed
U_PWR | 1 | on_car | Adjustable buck regulator with low-voltage cutoff | Pololu D30V30MALCMA item4872 | 15.2 x 25.4 x 9 | 39.95 | Manufacturer page checked 2026-09-05; rationed/backorders allowed | yes | https://www.pololu.com/product/4872 | Set and verify5.00V output; set6.2V backup cutoff; verify restart; load and thermal validation required
C_BULK | 1 | on_car | 1000uF 10V low-ESR radial electrolytic | Panasonic EEUFR1A102 | diameter10 x body16 |  | Price not verified | yes | https://industrial.panasonic.com/ww/products/pt/aluminum-cap-lead/models/EEUFR1A102 | Servo bus capacitor;5mm lead pitch; polarized; add insulated lead clearance
C_LOGIC | 1 | on_car | 100uF 10V radial electrolytic | Select stocked equivalent | measure chosen part |  | Price and exact SKU not verified | yes |  | Near MCU/camera rail; capacitor values are starting points to verify
C_BYPASS | 1 | on_car | 100nF ceramic 16V or higher | Select stocked through-hole equivalent | measure chosen part |  | Price and exact SKU not verified | yes |  | Near logic/camera rail
J_BAT | 1 | on_car | XT30 mating connector with 22AWG or thicker pigtail | AMASS-compatible keyed XT30 mate | measure chosen connector |  | Price and exact SKU not verified | yes |  | Match metal contact gender to actual pack; inspect polarity; leave battery leads original
F_IN | 1 | on_car | Inline DC fuse nominal4A plus insulated holder or leaded assembly | Select DC-rated part after inrush test | measure selected part |  | Price and exact SKU not verified | yes |  | Select adequate DC interrupt rating for LiPo and validate against wire and fuse time-current curves; not servo stall protection
HARNESS | 1 | on_car | Stranded22AWG supply wire and soldered distribution harness | Hookup wire / heatshrink / strain relief | route to actual chassis |  | Price not verified | yes |  | No servo current through ESP32 or solderless breadboard; servo signal wiring may be thinner; includes removable insulated 2-pin J_PWR disconnect for S2 supply, plus servo connectors
SW_EN | 1 | on_car | Small SPST switch across regulator EN-GND | Generic low-current signal switch | measure selected part |  | Price not verified | optional |  | Standby only; unplug XT30 for hardOFF; do not pass motor current through an unrated tiny slide switch
CHG1 | 1 | bench | 2S-capable balance charger with low-current setting | SkyRC B6neo SK-100198 | 70 x 50 x 31 |  | Price not verified | yes_unless_owned | https://www.skyrc.com/b6neo-series | Original model; choose LiPo2S balance4.20V/cell at0.4A; external tool; digital-power mode useful for cutoff calibration
CHG_ADAPTER | 1 | bench | XT60 charger-output to XT30 battery adapter | Polarity-checked mating lead | not on car |  | Price and exact SKU not verified | yes_unless_owned |  | Connect main and balance leads as documented by charger; physical gender must match actual ports
CHG_SUPPLY | 1 | bench | Compatible USB-C PD supply and cable | 12-20V PD support for original B6neo | not on car |  | Price and exact SKU not verified | yes_unless_owned | https://www.skyrc.com/b6neo-series | Plain5V USB supply is not sufficient for original model PD input; low-current battery charging does not require maximum80W supply
DMM | 1 | bench | Digital multimeter with DC voltage and current measurement | User-owned or suitable meter | not on car |  | Price not verified | yes_unless_owned |  | Needed to calibrate5V output and cutoff and check both cells; start powered tests with current-limited supply
LIPO_BAG | 1 | bench | LiPo charging and storage bag | Select reputable bag | not on car |  | Price not verified | recommended |  | Charge removed pack supervised on nonflammable surface; bag is not permission for unattended charging
QP_SENSE | 1 | on_car | Through-hole P-channel MOSFET battery-sense switch | Diodes BS250P | E-Line TO92-compatible; measure leadformed assembly | 1.75 | DigiKey checked2026-09-05; stock21254; last-time-buy2027-01-06 | yes | https://www.diodes.com/datasheet/download/BS250P.pdf | SourceVBAT_SW drain100k upper-divider gate100k-to-source; NRND; supplierhttps://www.digikey.com/en/products/detail/diodes-incorporated/bs250p/92630
QN_SENSE | 1 | on_car | Through-hole NPN battery-sense gate driver | onsemi 2N3904BU | TO92-3 |  | Price not verified | yes | https://www.onsemi.com/download/data-sheet/pdf/2n3904-d.pdf | EmitterGND base10k-fromGPIO7 and100k-toGND collector10k-toPMOSgate; selected pin1E2B3C
R_SENSE_100K | 3 | on_car | 100k ohm1percent axial resistor | Stocked metal-film equivalent | measure selected body |  | Price not verified | yes |  | Qty3:divider upper R1 / PMOS gate-source pullup / NPN base-ground pulldown
R_SENSE_33K | 1 | on_car | 33k ohm1percent axial resistor | Stocked metal-film equivalent | measure selected body |  | Price not verified | yes |  | Divider lower R2 toGND; ratio133/33 with100k upper
R_SENSE_10K | 2 | on_car | 10k ohm axial resistor | Stocked metal-film equivalent | measure selected body |  | Price not verified | yes |  | Qty2:GPIO7-toNPNbase and NPNcollector-toPMOSgate
C_SENSE | 1 | on_car | 100nF ceramic16V or higher | Stocked through-hole equivalent | measure selected body |  | Price not verified | yes |  | BAT_ADC/GPIO3 toGND; firmware wait20ms afterGPIO7HIGH before reading
PROTO_SENSE | 1 | on_car | Insulated perfboard for switched sensing and divider | Small cuttable perfboard | allow20 x 25 x 8 assembled provision |  | Price and final envelope not verified | yes |  | Mechanical envelope provisional; low-current signal circuit only; no customPCB fabrication needed
M_FL_RR | 2 | on_car | Owned MG90S-style 360 degree continuous servos | Exact owned variant TBD | Nominal 22.8 x 12.2 x 28.5; measure ears/shaft |  | Not priced; verify selected seller | owned | https://towerpro.com.tw/product/mg90s-3/ | Official page describes nominal MG90S; does not verify owned 360-degree variant. Retain supplied horns and shaft screws; verify 5 V suitability, current and neutral.
MCU_RX | 1 | on_car | LOLIN WEMOS S2 mini | ESP32-S2FN4R2 S2 mini V1.0.0 | 34.3x25.4; decorative height assumed |  | Not priced; verify selected seller | owned | https://www.wemos.cc/en/latest/s2/s2_mini.html | Headerless soldered leads recommended; fitted headers require taller packaging. Not C3/S3 mini.
CAM1 | 1 | on_car | Creator-linked analog FPV AIO camera | IDC-681H 25 mW 40CH 600TVL M7 | Provisional 20 x 20 x 24 total envelope |  | Not priced; verify selected seller | yes_for_FPV | https://robu.in/product/idc-681h-25mw-40ch-vtx-600tvl-m7-fpv-camera/ | Confirm actual dimensions, permitted supply voltage and current; no camera data connection to ESP32 needed; antenna remains attached.
V_RX | 1 | off_car | Analog 5.8 GHz video receiver | EWRF 5.8 GHz UVC OTG Android AV receiver | Off car |  | Not priced; verify selected seller | yes_for_FPV | https://robu.in/product/ewrf-5-8g-uvc-otg-android-av-phone-receiver/ | Creator-linked receiver. Check phone OTG/UVC/software compatibility; alternatively use compatible analog 5.8 GHz monitor/goggles. Wi-Fi alone cannot display analog FPV.
MCU_TX | 1 | controller | Second ESP32 development board | Classic ESP32 DevKit assumed | Off car |  | Not priced; verify selected seller | owned_if_available | https://docs.espressif.com/projects/arduino-esp32/en/latest/ | Transmitter sketch targets classic ESP32 pins 32/33 ADC, 27 deadman; use USB power bank.
JOY1 | 1 | controller | Two-axis spring-centered analog joystick | 3.3 V potentiometer joystick; exact module TBD | Off car |  | Not priced; verify selected seller | yes |  | Power at 3.3 V; calibrate endpoints and neutral; do not use 5 V analog signals.
DEADMAN | 1 | controller | Normally open momentary pushbutton | SPST button to GND | Off car |  | Not priced; verify selected seller | yes |  | Hold to enable motion; release stops. GPIO27 INPUT_PULLUP.
TX_POWER | 1 | controller | USB power bank and board-compatible cable | User-owned USB source | Off car |  | Not priced; verify selected seller | yes_unless_owned |  | Controller power separate from car; no onboard controller pack charger designed.
SERVO_HORNS | 2 | on_car | Factory servo horns and original shaft screws | Supplied with owned servos | Measure actual horn; model 20 mm disc assumed |  | Not priced; verify selected seller | owned |  | Never print a servo spline. Wheel radial slots have radius 5 to 11 mm; use at least two opposed attachment points.
HORN_FIX | 4 | on_car | Wheel-to-horn fasteners | Choose matching factory horn screws or M1.6/M2 bolts + nuts | Measure horn first |  | Not priced; verify selected seller | yes |  | Nominal wheel web 4.4 mm plus actual horn; choose engagement without case contact. Do not force M2 screws into unverified horn holes.
M2_DECK | 4 | on_car | Deck mount screws | 2 mm x 6 pan head plastic-tapping screws or coupon-verified M2 | 4 pieces |  | Not priced; verify selected seller | yes |  | 2.5 mm deck leaves 3.5 mm thread; 1.7 mm pilots in posts; print coupon and adjust pilot.
M2_SKID | 2 | on_car | Skid mount screws | 2 mm x 6 pan head plastic-tapping screws or coupon-verified M2 | 2 pieces |  | Not priced; verify selected seller | yes |  | 3 mm base leaves 3 mm thread in 4 mm deep, 1.6 mm pilot.
M2_CAM | 2 | on_car | Camera cradle screws | 2 mm x 5 pan head plastic-tapping screws or coupon-verified M2 | 2 pieces |  | Not priced; verify selected seller | yes |  | From below 2.5 mm deck nose into 2.5 mm cradle floor. Verify tip does not puncture camera foam.
TIES | 12 | on_car | Nylon cable ties | Approximately 2.5 mm wide; 100 mm long | Trim after fit |  | Not priced; verify selected seller | yes |  | Two per servo, two for battery, auxiliary hardware as needed; avoid crushing battery pouch or exposed PCB components.
FOAM | 1 | on_car | Thin nonconductive foam and insulation | 0.5–1 mm foam plus polyester/Kapton insulation | Trim to fit |  | Not priced; verify selected seller | yes |  | Under battery, servos, boards and camera; leave buck cooling and antenna area open.
VELCRO | 1 | on_car | Camera retention strap | Thin strap through 2.5 mm side windows | Measure chosen strap |  | Not priced; verify selected seller | yes |  | Use foam to adapt camera envelope. Fit is provisional.
PTFE | 1 | on_car | Low-friction skid contact tape | Thin PTFE tape | Two 12 mm pads |  | Not priced; verify selected seller | recommended |  | Smooth-floor prototype; optional rubber wheel bands increase grip but can increase diagonal turning load.
PRINT | 1 | printed | Eight supplied STLs | PETG or PLA; 0.4 mm nozzle | Base 81 x 100 x 27 mm; see mesh report |  | Not priced; verify selected seller | yes |  | Includes fit coupon. Print settings and fastener fit in docs/assembly.md. Not physically print-tested.
CALIPER | 1 | bench | Digital caliper | 0.1 mm or better useful resolution | Off car |  | Not priced; verify selected seller | yes_unless_owned |  | Needed for actual servo, camera, connector and board height measurements.

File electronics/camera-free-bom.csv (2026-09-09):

reference | quantity | status | item | unit_price_usd | source | notes
MCU | 1 | owned | LOLIN ESP32-S2 Mini |  | https://docs.wemos.cc/en/latest/s2/s2_mini.html | GPIO16 left; GPIO18 right; VBUS 5V; GPIO3/7 unwired; no onboard battery monitoring
SERVO | 2 | owned | MG90S-style continuous-rotation servo |  |  | Verify delivered wiring and neutral; servo current unknown
BUCK | 1 | owned | Large LM2596-style adjustable buck |  | https://www.ti.com/lit/ds/symlink/lm2596.pdf | Confirm IC; set5.00V; provisional2.8A load unverified; no LiPo cutoff
BAT | 1 | buy | Lumenier300mAh2S75C XT30 SKU10188 | 13.49 | https://www.racedayquads.com/products/lumenier-300mah-2s-75c-lipo-battery-xt-30 | 48x17x12mm18g; price/availability snapshot2026-09-07;7.4Vnominal8.4Vfull
J_BAT | 1 | reuse if XT30 otherwise buy | Mating XT30 pigtail with22AWG or thicker wire |  |  | Match contact gender to battery; owned photo cannot distinguish XT30/XT60; verify polarity
F_IN | 1 | candidate; validate | Littelfuse 0251004.MXL PICO II 251 axial fuse; 4 A provisional | 1.24 | https://www.digikey.com/en/products/detail/littelfuse-inc/0251004-MXL/700745 | 125VDC;300A DC interrupt;body7.11x2.80mm max; solder inline and insulate with strain relief; validate wire/fuse/inrush coordination; CAD nominal body; lead bends and insulation provisional; price snapshot2026-09-08
J_PWR | 1 | buy or fabricate | Insulated removable connector in S2 VBUS feed |  |  | Remove during USB programming; servo signals and battery also disconnected
C_BYPASS | 1 | buy | 100nF ceramic16V or higher |  |  | Across S2 VBUS and GND after J_PWR; short leads at S2 supply pads
HARNESS | 1 | buy or owned | Wire; servo extension leads; heatshrink |  |  | 22AWG minimum main power; insulated soldered joints; no perfboard; no motor current through S2
CHARGER | 1 | bench tool | 2S balance charger adjustable to0.30A |  |  | LiPo4.2V/cell;main XT30 plus3pin balance lead; not1S TP4056
DMM | 1 | bench tool | Digital multimeter |  |  | Verify polarity and 5V; manual per-cell checks before/between short runs with XT30 unplugged; no automatic low-voltage protection

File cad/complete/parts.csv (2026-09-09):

item | quantity | source_or_file | status
Integral-axle chassis | 1 | ../rolling/rolling-chassis.stl | Existing PETG fit prototype preserved
Passive bearing wheel | 2 | ../rolling/passive-wheel.stl | Existing press-fit wheel
MR83ZZ bearing | 2 | 3 x 8 x 3 mm nominal | Purchased bearing fits need coupons
Continuous servo | 2 | Owned MG90S-style units | Unmeasured clone geometry
Factory horn and supplied center screw | 2 | Included with owned servo | Assumed double-arm horn must be measured
Powered left wheel | 1 | powered-wheel-left.stl | New horn-pocket fit prototype
Powered right wheel | 1 | powered-wheel-right.stl | New horn-pocket fit prototype
Removable electronics carrier | 1 | electronics-deck.stl | New PETG prototype with integral holders
Flexible battery keeper | 2 | battery-band-tpu.stl | Print in TPU and verify pouch clearance
Battery protective padding | 1 | 0.8 mm nominal foam | Trim to actual pouch and cradle
LOLIN S2 Mini | 1 | ../../electronics/camera-free-bom.csv | Owned board; published outline
Large adjustable buck | 1 | ../../electronics/camera-free-bom.csv | Owned board; 43 x 21 x 14 mm provisional
Lumenier 300mAh 2S XT30 pack | 1 | ../../electronics/camera-free-bom.csv | Selected 48 x 17 x 12 mm pack
Harness connectors fuse and S2 bypass capacitor | 1 | ../../electronics/camera-free-bom.csv | Full quantities and electrical requirements in electronics BOM

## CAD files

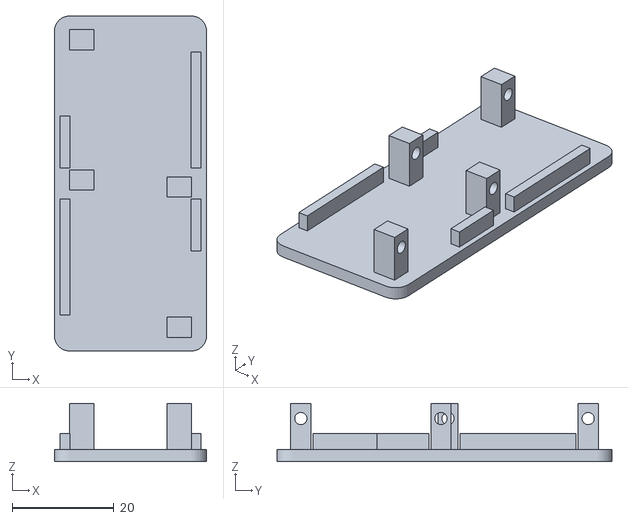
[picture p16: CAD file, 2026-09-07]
cad/compact/servo-pair-bracket.stl
30.0 x 66.0 x 11.5

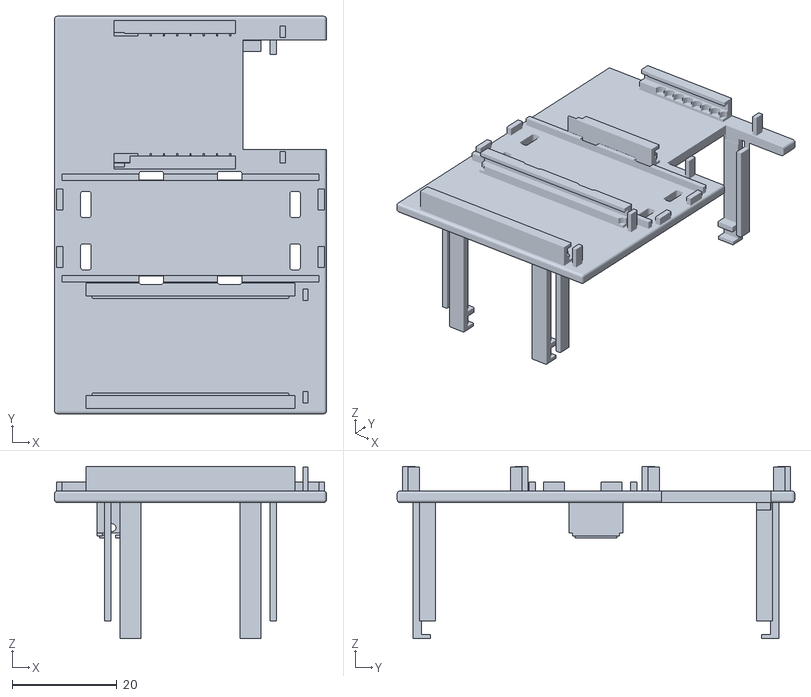
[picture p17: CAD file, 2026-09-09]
cad/complete/electronics-deck.stl
52.0 x 76.0 x 32.9

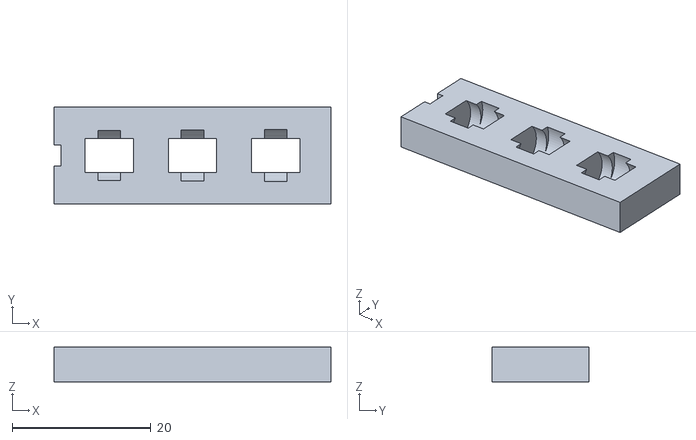
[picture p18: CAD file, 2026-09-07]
cad/rolling/bearing-fit-coupon.stl
40.0 x 14.0 x 5.00

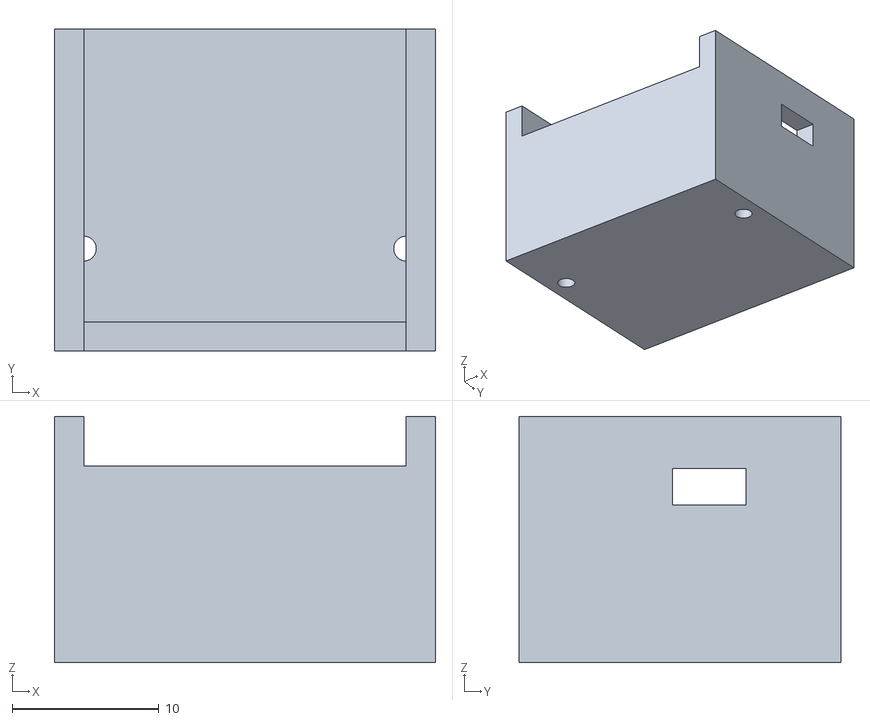
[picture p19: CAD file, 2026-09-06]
stl/03_camera_cradle.stl
26.0 x 22.0 x 16.8

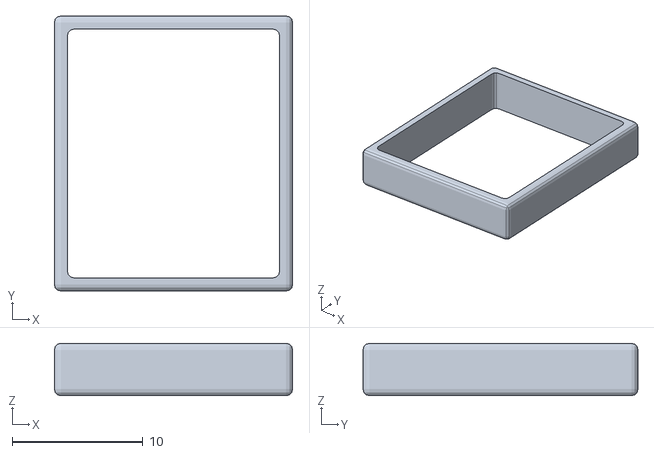
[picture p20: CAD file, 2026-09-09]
cad/complete/battery-band-tpu.stl
18.2 x 21.0 x 4.00

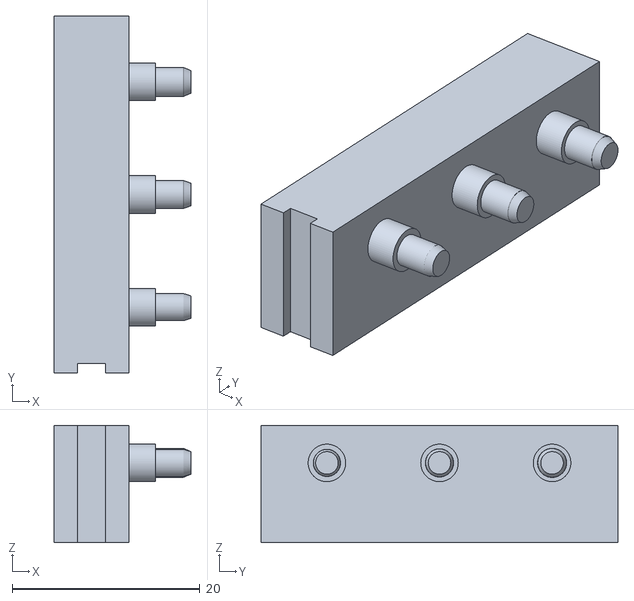
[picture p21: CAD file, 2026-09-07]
cad/rolling/axle-fit-coupon.stl
14.6 x 38.0 x 12.5

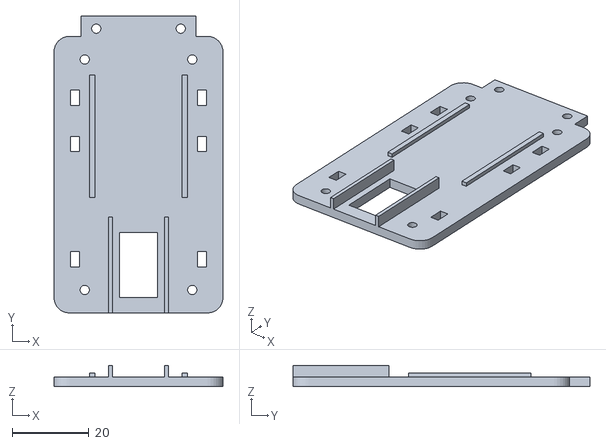
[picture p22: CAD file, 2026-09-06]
stl/02_electronics_deck.stl
44.0 x 77.3 x 5.55

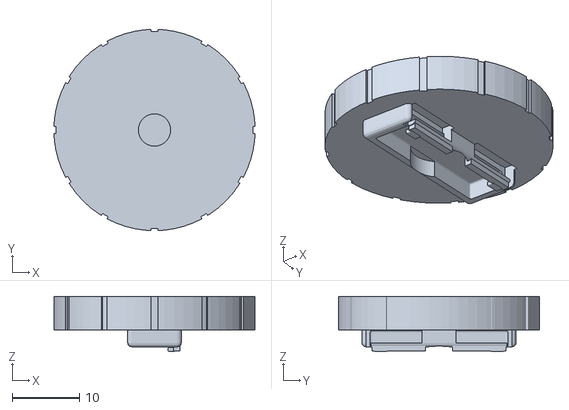
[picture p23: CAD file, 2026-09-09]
cad/complete/powered-wheel-left.stl
30.0 x 30.0 x 8.20

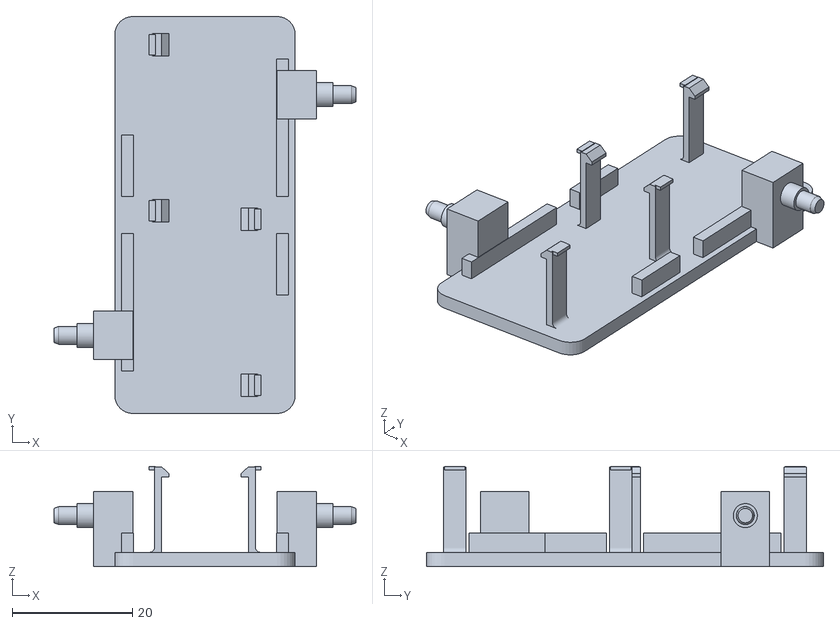
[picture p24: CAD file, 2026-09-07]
cad/rolling/rolling-chassis.stl
50.2 x 66.0 x 16.7

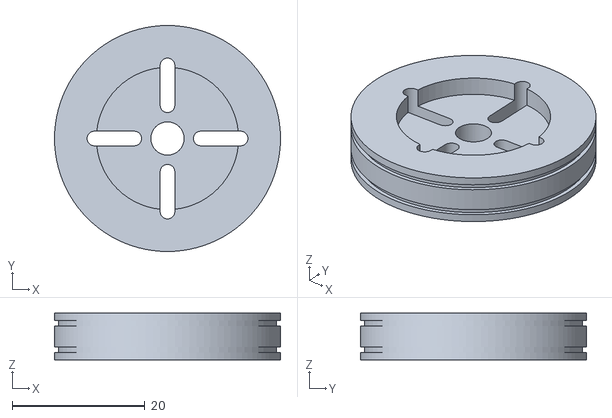
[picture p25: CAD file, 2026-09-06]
stl/06_drive_wheel.stl
34.0 x 34.0 x 7.00

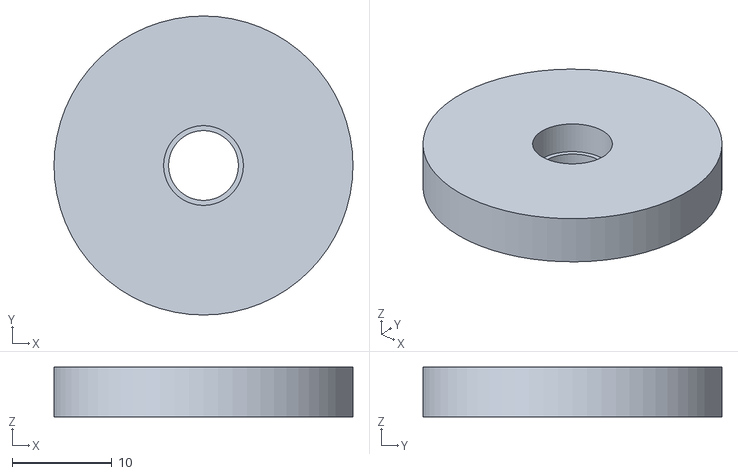
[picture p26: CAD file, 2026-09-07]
cad/rolling/passive-wheel.stl
30.0 x 30.0 x 5.00

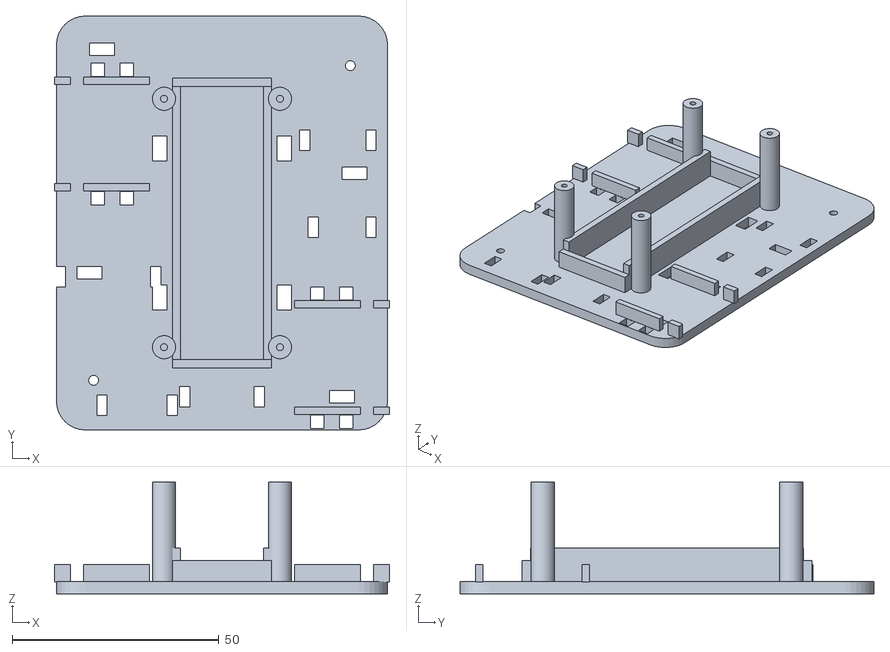
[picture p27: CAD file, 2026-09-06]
stl/01_chassis.stl
81.0 x 100.0 x 27.0

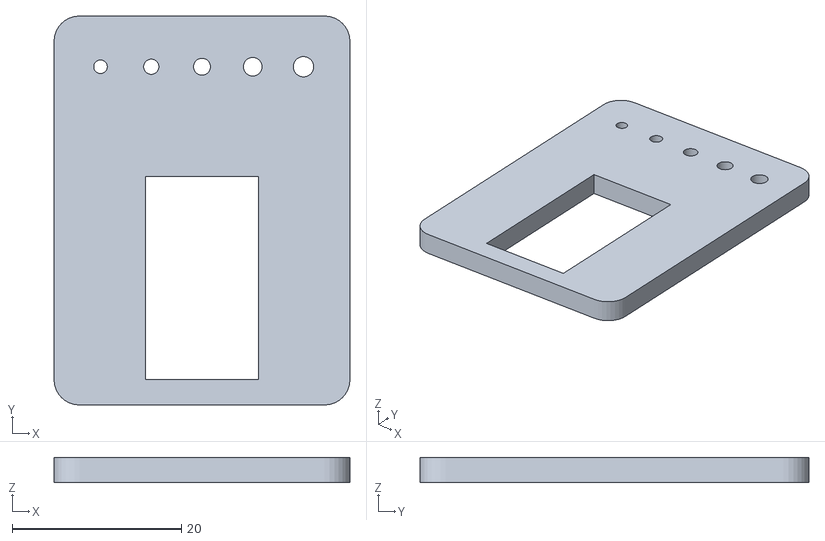
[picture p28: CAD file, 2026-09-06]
stl/08_fit_coupon.stl
35.0 x 46.0 x 3.00

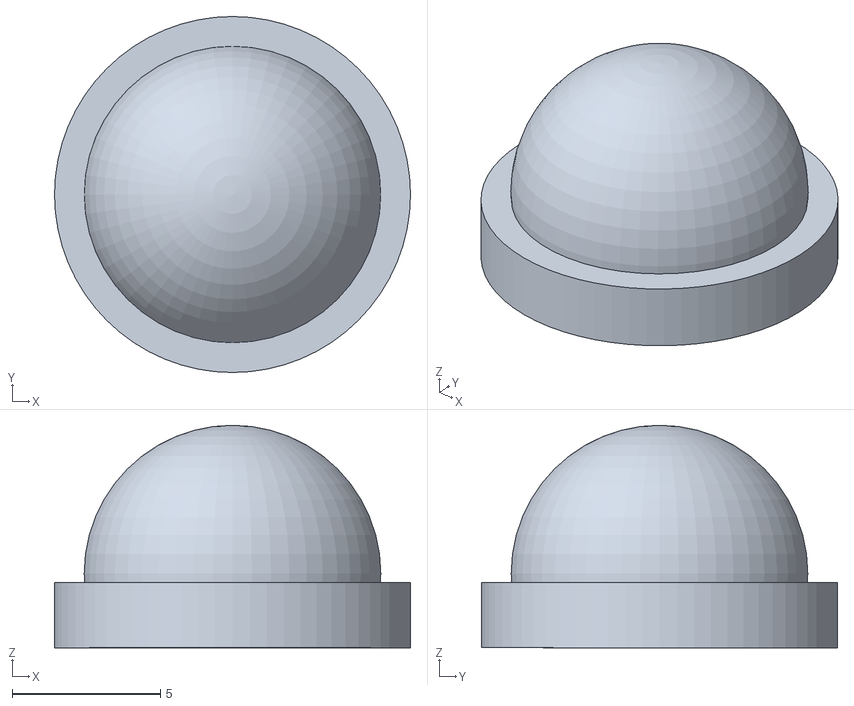
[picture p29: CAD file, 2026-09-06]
stl/04_skid_foot.stl
12.0 x 12.0 x 7.50

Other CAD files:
cad/complete/powered-wheel-right.stl
stl/07_drive_wheel.stl
stl/05_skid_foot.stl
cad/compact/servo-pair.blend
cad/complete/complete-spy-car.blend
cad/complete/spy-car-v0.6.2-no-extra-capacitor.blend
cad/components.blend
cad/diagonal-spy-car.blend
cad/rolling/rolling-chassis.blend

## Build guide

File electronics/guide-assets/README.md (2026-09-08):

# Wiring-guide image sources

These are factual component references, not exact photographs of every delivered part. Third-party photos retain their owners' rights and are **excluded from this repository's MIT license**. They are reproduced with attribution in the wiring guide for identification. Do not treat them as original open-source artwork.

| File | Credit and source |
| --- | --- |
| `s2-mini-top.jpg` | WEMOS / LOLIN, [S2 Mini documentation](https://docs.wemos.cc/en/latest/s2/s2_mini.html), [original top-side photograph](https://docs.wemos.cc/en/latest/_images/s2_mini_v1.0.0_1_16x16.jpg) |
| `servo.jpg` | TowerPro, [MG90S product](https://towerpro.com.tw/product/mg90s-3/), [original photograph](https://towerpro.com.tw/wp-content/uploads/2014/08/MG90S-1B.jpg). Appearance reference only: this image does not establish that the user's servos are genuine, continuous-rotation, or electrically identical. |
| `battery.webp` | Lumenier / RaceDayQuads, [300 mAh 2S XT30 product](https://www.racedayquads.com/products/lumenier-300mah-2s-75c-lipo-battery-xt-30). [Original image](https://cdn.shopify.com/s/files/1/1285/4651/files/lumenier-lumenier-300mah-2s-75c-lipo-battery-xt-30-battery-32426879811697.webp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) |
| `owned-buck.jpg`, `owned-buckboost.jpg` | User-supplied IMG_3224.JPG; orientation normalized and cropped for document placement. IC markings are not established by this photograph. |
| `owned-connectors.jpg` | User-supplied IMG_3225.JPG; orientation normalized and cropped for document placement. XT30 versus XT60 is unconfirmed. |

Research snapshot: 2026-09-07. Images were not generated by AI. Terminal markers and connecting wires are vector annotations generated by `../build_wiring_guide.py`.

Rebuild from the repository root with `python3 electronics/build_wiring_guide.py` (ReportLab and Pillow). Final output: `output/pdf/spy-car-wiring-guide.pdf`. The source and original project diagrams follow the repository license; embedded third-party imagery does not.

## Fuse added September 8, 2026

`fuse-pico-251.jpg`: Littelfuse PICO II 251 family reference photograph supplied by [DigiKey on the 0251004.MXL listing](https://www.digikey.com/en/products/detail/littelfuse-inc/0251004-MXL/700745), [original image](https://mm.digikey.com/Volume0/opasdata/d220001/derivates/1/002/661/086/PICO%20II%20R251%20SERIES_sml%28200x200%29.jpg). The listing explicitly calls it a representation. It identifies the axial fuse style; it does not establish markings on the delivered 4 A part. Unmodified photograph; rights remain with the image owner and it is excluded from the MIT license. Electrical and mechanical values come from the [Littelfuse 251 datasheet](https://www.littelfuse.com/assetdocs/littelfuse_fuse_251_253_datasheet.pdf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). Pages 1 and 6 show the photo.

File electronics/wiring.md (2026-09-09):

# Camera-free wiring and commissioning

**Current selection: the owned large LM2596-style adjustable buck, a Lumenier 300 mAh 2S LiPo with XT30, the S2 Mini, and two continuous-rotation servos.** This is a soldered harness and an untested electrical assembly. Use the [picture wiring guide](../output/pdf/spy-car-wiring-guide.pdf) and [current camera-free BOM](camera-free-bom.csv). The earlier Tattu/Pololu/FPV proposal in `docs/power.md` and root `BOM.md` is historical and does not describe this wiring.

The battery is 7.4 V nominal and 8.4 V fully charged. Adjust the converter output to **5.00 V before connecting any loads**. “LM2596-style” identifies the module family, not a verified manufacturer, continuous-current rating or protection specification. Confirm the markings and polarity on the owned board. No charger, servo motor driver or custom PCB is required on the car; each continuous servo contains its own motor driver.

Browser remote control runs on the existing S2 Mini and adds no wiring or hardware. A phone replaces the optional ESP-NOW handheld. See [browser setup](../firmware/README.md#browser-remote-control); manual battery checks and the USB-isolation requirements below still apply. There is no battery-sensing perfboard in the current build.

## Car topology

```mermaid
flowchart LR
    BAT["Lumenier 300 mAh 2S LiPo: up to 8.4 V"] --> XT["XT30: manual hard OFF"]
    XT --> F["Input fuse"]
    F --> VB["VBAT_SW: fused raw battery positive"]
    VB --> BUCK["Owned LM2596-style buck: OUT+ relative to OUT- = 5.00 V"]
    BUCK --> BUS["5V_BUS: soldered star distribution"]
    BUS --> LS["Front-left continuous servo supply"]
    BUS --> RS["Rear-right continuous servo supply"]
    BUS --> JP["Removable J_PWR feed"]
    JP --> MCU["S2 Mini VBUS / 5V"]
    MCU -- "GPIO16 signal" --> LS
    MCU -- "GPIO18 signal" --> RS
    XT -. "battery negative" .-> G["Common GND"]
    G -. "buck IN− / OUT−" .-> BUCK
    G -. "return" .-> LS
    G -. "return" .-> RS
    G -. "return" .-> MCU
    USB["USB programmer: battery unplugged, J_PWR removed, servo signals unplugged"] -.-> MCU
```

`VBAT_SW` is the existing firmware/documentation net name for the fused battery feed; it does not imply an automatic power switch. Ground is a continuous electrical connection between battery negative, buck input/output negative, both servo grounds and S2 Mini GND. Confirm input-negative/output-negative continuity with the converter unpowered. Keep servo current in the power harness, not through the S2 board, a GPIO, USB connector or solderless breadboard. Keep the ESP32 antenna away from the converter and motor wiring.

## Car net table

| Net / component label | Connect to | Requirement |
|---|---|---|
| Battery positive, XT30 harness side | Input fuse, then `VBAT_SW` | Preserve original battery leads; verify mating connector polarity |
| `VBAT_SW` | Buck `IN+` | Raw 2S voltage; never connect directly to a servo, S2 VBUS, 3V3 or GPIO |
| Battery negative | Buck `IN−` and common ground | Short 22 AWG or thicker supply wiring |
| Buck `OUT+` | `5V_BUS` | Set and measure **5.00 V** with all loads disconnected first |
| Buck `OUT−` | Common ground / soldered return distribution | Separate return branches for both servos and S2 |
| `5V_BUS` | Both servo positive supply inputs; `J_PWR` | Separate branches; no motor current through the MCU board |
| `J_PWR` removable feed | S2 Mini **VBUS / 5V** | Remove this feed before USB programming |
| S2 Mini `GND` | Common ground | Required for servo PWM signaling |
| S2 Mini **GPIO16** | Front-left servo signal | Firmware `LEFT_SERVO_PIN`; initially direct 3.3 V logic |
| S2 Mini **GPIO18** | Rear-right servo signal | Firmware `RIGHT_SERVO_PIN`; **not GPIO17** |
| Both servo grounds | Common ground | Identify supply, ground and signal from the actual units; colors/contact order are not proof |
| C_BYPASS **100 nF ceramic** | S2 `VBUS` after `J_PWR` to GND | Short leads at the S2 supply pads |
| Battery three-contact balance connector | Compatible 2S balance charger / manual per-cell meter | Verify connector orientation and cell taps; never connect it directly to S2 pins |

Use a DC-rated input fuse in an insulated assembly selected for the battery fault current, wiring and measured inrush; do not call the fuse servo-stall protection. Keep supply/return wires short and use heatshrink and strain relief. The extra external **220 µF bulk capacitor is omitted** from this POC. Retain the **100 nF ceramic bypass** at S2 VBUS/GND after `J_PWR`, and leave all capacitors already fitted to the buck in place. The small bypass does not replace bulk energy storage or establish that servo startup/reversal will keep the rail stable; validate the assembled supply under load. Use insulated soldered joints for power distribution. No perfboard, sensing transistors, sensing resistors, ADC filter, or GPIO3/GPIO7 wires are fitted.

## Exact S2 Mini pads

The following positions are verified against the [official WEMOS pinout](https://docs.wemos.cc/en/latest/_images/s2_mini_v1.0.0_4_16x9.jpg). Hold the **component side toward you, antenna at the top, USB-C at the bottom**. Count only the eight small electrical pads in a column, starting at the top; ignore the large mounting holes. The underside is mirrored. Confirm the owned board revision and underside silkscreen before soldering.

| Required net | Physical pad in that top-view orientation | Neighbor that helps identify it |
|---|---|---|
| Regulated 5 V input | **Right outer column, row 8: VBUS** | Right inner row 8 is GPIO15; do not use it for power |
| GND | **Right outer column, row 7** | Right inner row 7 is also GND |
| Left servo signal GPIO16 | **Right outer column, row 6** | Right inner row 6 is GPIO17; not the right-servo signal |
| Right servo signal GPIO18 | **Right outer column, row 5** | Right inner row 5 is GPIO21 |

For a second check, the complete right outer column from top to bottom is **39, 37, 35, 33, 18, 16, GND, VBUS**. GPIO runs at 3.3 V. The genuine board's [V1.0.0 schematic](https://docs.wemos.cc/en/latest/_static/files/sch_s2_mini_v1.0.0.pdf) directly connects the header VBUS and USB VBUS net. Before plugging in powered USB, **unplug the battery, remove `J_PWR`, and unplug both servo signals**. Removing the battery alone does not isolate an attached buck/output harness from USB backfeed. Restore external wiring only after removing USB power. Check clone boards separately.

For routine receiver programming, use the [parked Wi-Fi update mode](../firmware/README.md#wireless-receiver-updates) after its initial USB installation. With **USB unplugged**, the battery, buck, `J_PWR`, and calibrated servo connections can stay in place; lift the wheels and verify behavior during reboot. The built-in BOOT/0 button enters maintenance after startup, so this adds no switch or wiring. The USB isolation instructions above and in the illustrated PDF remain necessary for initial setup and recovery. `J_PWR` is our name for a mating insulated connector in the positive 5 V feed to VBUS, not a component built into the S2 Mini. The two connector halves remain joined during normal battery-powered use; ground is continuous. Its exact connector family and package are not selected, so the Blender housing is a labeled allowance, not a purchase specification.

**Current versus planned Wi-Fi updates:** browser driving on configured home Wi-Fi works now. The current updater always creates `SpyCar-Update`, reached at `http://192.168.4.1/update` after holding BOOT/0 for three seconds after startup. The agreed home-Wi-Fi-first updater at `http://spy-car.local/update`, with AP fallback, is a planned software change; do not expect that route to work yet. Neither approach needs a change to this power wiring.

## Load and shutdown limits

The provisional 5 V peak budget is **2.8 A**: 1.2 A per servo plus 0.4 A for the S2. These are planning allowances, not measured specifications for the owned servos. The converter's suitability remains unverified even if its listing or IC says “3 A.” Check both servos starting and reversing together, voltage at the S2/servo connectors, and converter temperature at the full pack and at 7 V input on a bench supply. A multimeter can miss short dips; use a scope if available. Do not hold the servos stalled. Reduce the load or replace the converter if the rail falls out of regulation, the board resets or the module overheats.

## Manual battery checks - no onboard low-voltage protection

The current POC deliberately removes the battery-sensing circuit. **The receiver does not measure battery voltage or stop for a low battery.** There is no battery value to calibrate, no battery telemetry, no alarm and no automatic low-voltage disconnect. The fuse protects against sufficiently large overcurrent; it cannot protect against over-discharge. Joystick release and lost-link stopping still work, but they do not disconnect power.

Use your multimeter before and between short, attended runs, with the **XT30 unplugged from the car**:

1. Select DC volts with leads in COM and V, never the current socket/range. Prefer an insulated mating balance breakout so probe tips cannot short adjacent contacts.
2. Identify the balance connector's three taps: pack negative, cell midpoint, pack positive. Do not assume a physical left/right orientation or wire colors. Across the two end taps is total pack voltage; each adjacent pair measures one cell. Verify polarity and use the actual pack/charger instructions to identify contacts.
3. Record **each cell separately**. A healthy total voltage alone can hide a depleted cell. Start with a correctly balance-charged pack and use very short trials while establishing real runtime.
4. For this attended POC, **end the session when either cell is at or below 3.7 V at rest**, or earlier if the pack maker specifies a higher limit. This is a deliberately early project stopping point, not a manufacturer minimum or a guarantee against dips during a run. If either cell is already 3.5 V or lower, do not do another run; recharge appropriately. Do not run down to the absolute discharge limit.
5. Keep XT30 disconnected whenever parked, measuring, charging or storing. Stop immediately for abnormal heating, puffing, unexpected slowing or resets; do not use those symptoms as a normal low-battery indicator.

Periodic checks cannot catch a rapid drop or weak cell between measurements. No safe fixed runtime has been measured for this build. If you want longer runs without these interruptions, add a suitable per-cell monitor/cutoff in a future revision. Use a compatible external **2S LiPo balance charger**, correct pack settings and the manufacturer's instructions; never a 1S TP4056 charger. For OTA, start with a freshly balance-charged pack, keep wheels lifted and USB unplugged; firmware does not check the battery before or during an update.

## Optional handheld transmitter

Use an **original ESP32 development board** with GPIO32 and GPIO33 exposed for this pin map. This is a second controller; the same map is not interchangeable with the S2 Mini. A simple two-axis analog joystick and normally-open momentary deadman switch are sufficient. Power the transmitter through its own USB supply for the prototype.

```mermaid
flowchart LR
    U["USB supply"] --> TX["Original ESP32 DevKit"]
    TX -- "3V3" --> JOY["Analog joystick"]
    JOY -- "throttle wiper" --> A["GPIO32"]
    JOY -- "steering wiper" --> B["GPIO33"]
    D["Normally-open deadman button"] -- "pressed connects to GND" --> C["GPIO27: INPUT_PULLUP"]
    A --> TX
    B --> TX
    C --> TX
    TX -. "ESP-NOW paired radio link" .-> RX["Car S2 Mini"]
```

| Transmitter pin / net | Connect to |
|---|---|
| ESP32 `3V3` | Joystick supply; **do not use 5 V** |
| ESP32 `GND` | Joystick ground and one deadman switch contact |
| **GPIO32** | Joystick throttle-axis wiper, firmware `THROTTLE_PIN` |
| **GPIO33** | Joystick steering-axis wiper, firmware `STEERING_PIN` |
| **GPIO27** | Other contact of a normally-open momentary switch; firmware uses internal pull-up |
| Joystick click switch | Leave unconnected unless intentionally used as the deadman and verified |

GPIO32/33 are ADC1 inputs on the original ESP32, allowing the joystick to avoid ADC2/Wi-Fi contention. [Espressif DevKitC reference](https://documentation.espressif.com/api/resource/path/docs/projects/esp-dev-kits/en/latest/esp32/esp32-devkitc/user_guide.html)

No ground wire runs between handheld and car: they have separate supplies and communicate by radio. Calibrate each joystick's minimum, center, maximum, direction and dead zone in the transmitter config. Verify that a released or disconnected deadman means stop. Store your actual peer addresses and unique encryption keys locally; never publish those credentials in the public repository.

## If a servo rejects 3.3 V signals

First confirm shared ground, 5 V at the servo connector, correct pulse timing and the delivered servo's input specification. If it requires a higher logic-high level, add a **SN74AHCT125N** buffer powered from the same regulated 5 V rail, with 100 nF bypass at VCC/GND. Its TTL-compatible input recognizes a 3.3 V high; AHCT is deliberate, and an arbitrary HC buffer is not an equivalent choice. [TI datasheet](https://www.ti.com/lit/ds/symlink/sn74ahct125.pdf)

Use these **signal names**, locating the exact package pins from TI's diagram: GPIO16 → `1A`, `1Y` → left signal; GPIO18 → `2A`, `2Y` → right signal; active channels' `/OE` → GND. Add 10 kΩ pull-downs to the two used A inputs so reset inputs do not float. Disable unused channels by taking `/OE` to VCC and tie their A inputs to GND; leave unused Y outputs open. Never connect a 5 V Y output to the ESP32. Disconnect signals while independently programming an unpowered buffer/servo assembly; this optional circuit has not been added to the baseline mechanical model or validated on the user's servos.

## Staged bench test

1. **Inspect unpowered.** Confirm actual board labels, battery connector polarity, and the two converter input/output pairs. Check for supply-to-ground shorts. Leave wheels off and keep the XT30 disconnect accessible.
2. **Flash using isolated USB power.** Unplug the battery, remove `J_PWR`, and unplug both servo signals. Flash the S2 receiver and configure your private Wi-Fi settings for browser driving. A second controller and pairing keys are needed only for optional ESP-NOW mode. Servo calibration deliberately remains false until tested; do not enable it merely to force motion.
3. **Commission the buck alone.** Disconnect every load. Apply a current-limited input supply within the 2S operating range, identify the output-adjustment potentiometer, and set `OUT+` to `OUT−` to 5.00 V. Recheck across the expected input range, including near 7 V. No battery-cutoff setting or exposed enable/power-good interface is assumed for this owned module.
4. **Commission the receiver.** Remove USB, restore `J_PWR`, and use the current-limited supply. Confirm 5.00 V at VBUS and the correct firmware configuration for this manual-check build. Leave GPIO3 and GPIO7 unwired. Keep servo outputs disconnected until the next step.
5. **Commission one servo at a time.** Confirm continuous rotation, actual neutral and direction using small pulse offsets with the shaft unloaded. Missing PWM is not a guaranteed stop for every clone. Verify 3.3 V signal compatibility and keep the power disconnect reachable. Record each neutral before enabling drive.
6. **Check browser control with wheels lifted.** Open `http://spy-car.local/` on the same configured home Wi-Fi. Verify startup, calibrated neutral, joystick release, tab hiding and Wi-Fi loss. Confirm forward/reverse and both turn directions. A fresh hold must be required after reconnecting; servo calibration must be verified. Optional ESP-NOW mode separately requires paired keys and handheld checks.
7. **Check the manual-check workflow.** Confirm the receiver does not claim battery voltage or low-battery protection. Practice unplugging XT30 and measuring both cells without bridging contacts. Record an initial short-run duration and per-cell voltages; no runtime estimate is a substitute for measurements.
8. **Validate realistic combined load.** Exercise both servos and Wi-Fi together, measure current, observe supply dips and check the buck's temperature in its intended mounting. Test near 7 V input as well as at full input voltage. The 2.8 A budget and the decision to omit extra bulk capacitance remain unvalidated until these checks pass. If the rail dips or the S2 resets, stop the test and revisit the power design.
9. **Finish and test briefly.** Insulate and strain-relieve joints, keep screws/sharp edges away from the pouch, and perform a short supervised smooth-floor run. Record each cell voltage and measured runtime. Unplug XT30 after every run and remove the pack for balance charging or storage.

Actual servo current, neutral, logic compatibility, USB power isolation, radio failsafe and converter thermal/load performance remain hardware validation tasks. CAD renders and successful code compilation do not establish these results.

## Fuse photograph and the under-deck components

The illustrated guide shows a Littelfuse PICO II 251 family reference photograph on pages 1 and 6. A compact **candidate**, not a tested final selection, is [0251004.MXL](https://www.digikey.com/en/products/detail/littelfuse-inc/0251004-MXL/700745): 4 A very fast acting, rated 125 V DC with 300 A DC interrupt capacity. The [manufacturer drawing](https://www.littelfuse.com/assetdocs/littelfuse_fuse_251_253_datasheet.pdf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) gives a 7.11 mm body length and 2.80 mm maximum diameter. Leave additional room for leads, insulation and strain relief. Validate the candidate against measured inrush, wiring and prospective fault current. This is not an instantaneous 4 A limiter.

Wire this non-polar axial fuse in series near the battery connector in the **positive harness lead**, before the buck. Solder and insulate it with strain relief; an axial part does not need a cartridge holder. It is not resettable. The updated Blender fuse follows the nominal 7.11 mm body length and 2.80 mm maximum diameter, with 0.64 mm leads. Lead bends and insulation are assembly allowances; the retained loose carrier and strain relief need a physical fit check.

The former battery-sensing perfboard and all of its parts have been removed. The extra external 220 µF bulk capacitor and its printed holder are also removed. The retained 100 nF ceramic bypass connects directly across S2 VBUS and GND after `J_PWR`; keep the converter's onboard capacitors fitted. Neither the bypass nor the fuse provides charging or an automatic low-voltage power disconnect.

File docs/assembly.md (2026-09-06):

# Prototype printing and assembly

This is an **unbuilt fit prototype**. The meshes have been generated in Blender; neither a slicer preview nor a physical print/drive test has been completed. Hardware dimensions and the exact continuous-servo variant still require the [measurement checklist](measurement-checklist.md). Read [mechanics.md](mechanics.md), [power.md](power.md), and [wiring.md](../electronics/wiring.md) before assembly.

## Print files and orientation

STLs are in millimetres and already placed at Z=0 in the intended orientation. Import at 100% scale. Do not apply the assembly model's world coordinates to the individual STLs.

| Order | File in `stl/` | Quantity | Build-plate face |
| --- | --- | --- | --- |
| First | `08_fit_coupon.stl` | 1 | Broad flat underside |
| 1 | `01_chassis.stl` | 1 | Flat chassis underside; posts upward |
| 2 | `04_skid_foot.stl`, `05_skid_foot.stl` | 1 each | Flat mounting flange down; dome upward |
| 3 | `06_drive_wheel.stl`, `07_drive_wheel.stl` | 1 each | Flat outer wheel face down; horn recess upward |
| 4 | `02_electronics_deck.stl` | 1 | Flat deck underside; support rails upward |
| 5 | `03_camera_cradle.stl` | 1 | Flat cradle underside; open side upward |

Start with PLA for a fit prototype or PETG for the assembled chassis, a 0.4 mm nozzle, 0.2 mm layers, four walls, five top/bottom layers, and approximately 25% infill. Use the same material and slicer profile for the coupon and mating parts. These are starting settings, not demonstrated strength or printability results. Inspect every part in the slicer: the posts need continuous perimeter walls, the wheel slots must remain open, and the cradle's small horizontal strap openings may need bridging or localized support. The convex skid surface will show layer steps; smooth it before fitting optional PTFE wear tape. Do not sand parts while installed near the battery or electronics.

The coupon provides a 13.4 × 24 mm nominal rectangular opening and five holes of 1.6, 1.8, 2.0, 2.2 and 2.4 mm diameter in order along its row. Identify that order in Blender before testing. It checks printer fit and screw pilot behavior; it is not a complete servo pocket or horn mating test. Print one wheel separately to validate the actual horn fit.

## Nominal fasteners and retention

Lengths below are measured under the screw head. Printed pilot holes are not modeled threads. Use small pan-head plastic-tapping screws, or properly tap a coupon and use matching machine screws. Do not treat an M2 machine screw and an arbitrary 2 mm tapping screw as interchangeable. Calibrate the chosen fastener on the coupon; enlarge a pilot carefully only when necessary.

| Joint | Quantity | Initial hardware choice | Nominal engagement and limitation |
| --- | --- | --- | --- |
| Upper deck to chassis posts | 4 | 2 mm diameter × 6 mm plastic-tapping screws | Through 2.5 mm deck into about 3.5 mm of post; modeled pilot diameter 1.7 mm |
| Skid feet to chassis | 2 | 2 mm diameter × 6 mm plastic-tapping screws | Insert from inside chassis, through 3 mm floor into about 3 mm of foot; modeled pilot diameter 1.6 mm; longer screws risk breaking through the dome |
| Camera cradle to deck nose | 2 | 2 mm diameter × 5 mm plastic-tapping screws | Insert upward from beneath the deck, through 2.5 mm deck into 2.5 mm cradle floor; pilot diameter 1.7 mm; tips must not protrude into camera space |
| Printed wheel to purchased horn | At least 2 per wheel | Small through-bolts, washers and locknuts matched to the actual horn; M1.6 × 8 mm is only a starting candidate | Nominal web 4.4 mm + representative horn 1.2 mm = 5.6 mm before washer/nut; verify horn hole clearance, engagement, shaft/case clearance and weight balance |
| Purchased horn to servo shaft | 1 per servo | Original supplied center screw | Retain the original pitch and length; do not substitute a generic M2 screw |

The modeled horn holes are illustrative. Do not force an M1.6 bolt through a smaller supplied hole. Choose compatible hardware after measurement; modify the printed wheel rather than assuming the horn is safe to drill. Use opposite horn holes and place any protruding hardware where a full rotation clears the case. The 5 mm wheel center access hole is for the screwdriver, not a printed spline.

Allow at least four approximately 2.5 mm-wide nylon ties for the two servos, soft approximately 5 mm-wide straps for the battery slots, and narrow ties/straps for the boards and auxiliary parts. Use thin insulating foam or other suitable electrical insulation beneath boards and a soft approximately 1 mm pad below the pouch. Select strap thickness to fit the slots. Keep buckles away from the pouch, components and moving wheels. Do not tighten a rigid tie directly against an unpadded LiPo pouch.

## Assembly sequence

1. **Print and check the coupon.** Check the selected screws by hand and measure printed openings. Update core envelopes in `cad/parameters.json` and the corresponding mating geometry in `cad/build.py` as needed; layout coordinates and detailed mounts are not all automatic. Regenerate and recheck before printing the chassis.
2. **Dry-fit the bare parts.** Remove sharp edges and debris. Check that the flat deck rests on all four posts and that neither servo touches a post. Confirm ear clearance at the notches in the servo stop walls. Do not install the battery during drilling, tapping or trimming.
3. **Install both skid feet.** Place each flat flange against the chassis underside and insert its screw from above. Tighten lightly. The dome tips and nominal 34 mm drive wheels should contact the same level plane; final adjustment depends on printer error and grip bands.
4. **Restrain the servos.** Set the front-left and rear-right servos on the chassis in the orientations shown in `cad/diagonal-spy-car.blend`. Thread two independent ties per servo through the paired floor slots and over its body. Keep ties clear of the mounting flange and harness exit. They should prevent case movement without crushing the housing.
5. **Fit the horns and wheels.** With the pack disconnected, bolt each printed wheel flat against its supplied horn. Seat the horn on the servo spline and install the original retaining screw through the center access hole. Rotate each wheel fully by hand without forcing the servo gears. Check screw ends, case clearance and wobble. Add modest-grip bands only after the basic fit works.
6. **Install the lower auxiliary hardware.** Secure and insulate the voltage-sense perfboard, capacitors, fuse and connectors in the reserved volumes. The rendered auxiliary shapes are packaging allowances, not fabricated circuit boards. Keep capacitor bodies from resting on unsupported leads and cover all exposed supply joints. Route the fuse and connector leads without entering either wheel's sweep. The balance connector must remain insulated and accessible for external balance charging.
7. **Wire and calibrate off the battery.** Follow `electronics/wiring.md` and `docs/power.md` using the specified commissioning process. Program the S2 before securing its strap. The packed layout does not reserve a straight USB cable insertion corridor: release and lift the S2 for USB programming, with external battery power disconnected. Do not pry a connector against the regulator.
8. **Assemble the upper deck while accessible.** Attach the camera cradle using the two upward-facing screws from below; then place insulated boards on their support rails and strap them without touching switches, USB or antenna traces. Fit the camera with soft padding and its retention strap. Verify camera power requirements before plugging it in. Keep its antenna and ventilation clear.
9. **Install the padded, removable battery.** Route the soft straps before closing the deck. Hold the pack firmly enough to prevent sliding, with no sharp object or screw tip pointing at the pouch. Leave the XT30 disconnect reachable and enough slack to remove the pack without pulling solder joints.
10. **Close and inspect.** Fit the four deck screws. Confirm no trapped wires, trapped balance lead, loose metal, wheel contact or battery compression. Check the four contact points on a flat surface; shim supports gently if needed without unloading either powered wheel.
11. **Commission with the wheels raised.** Perform polarity, regulation, low-voltage behavior, neutral, direction and radio failsafe checks from the electrical documentation. Only then attempt a slow smooth-floor test. Measure turn current and inspect heat, screw retention and body movement. This diagonal layout must scrub sideways to turn, so successful straight driving does not validate turning.

Keep the pack removable and use the specified external balance charger. This assembly does not add onboard charging. Record measured dimensions, chosen fastener details, print settings and test results before describing a later revision as build-tested.

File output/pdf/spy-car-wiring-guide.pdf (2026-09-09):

DIAGONAL SPY CAR / CAMERA-FREE PROTOTYPE

# Connect the car

Read the named terminals here; page 2 locates the actual solder pads. All grounds connect together. Crossings connect only where marked with a dot.

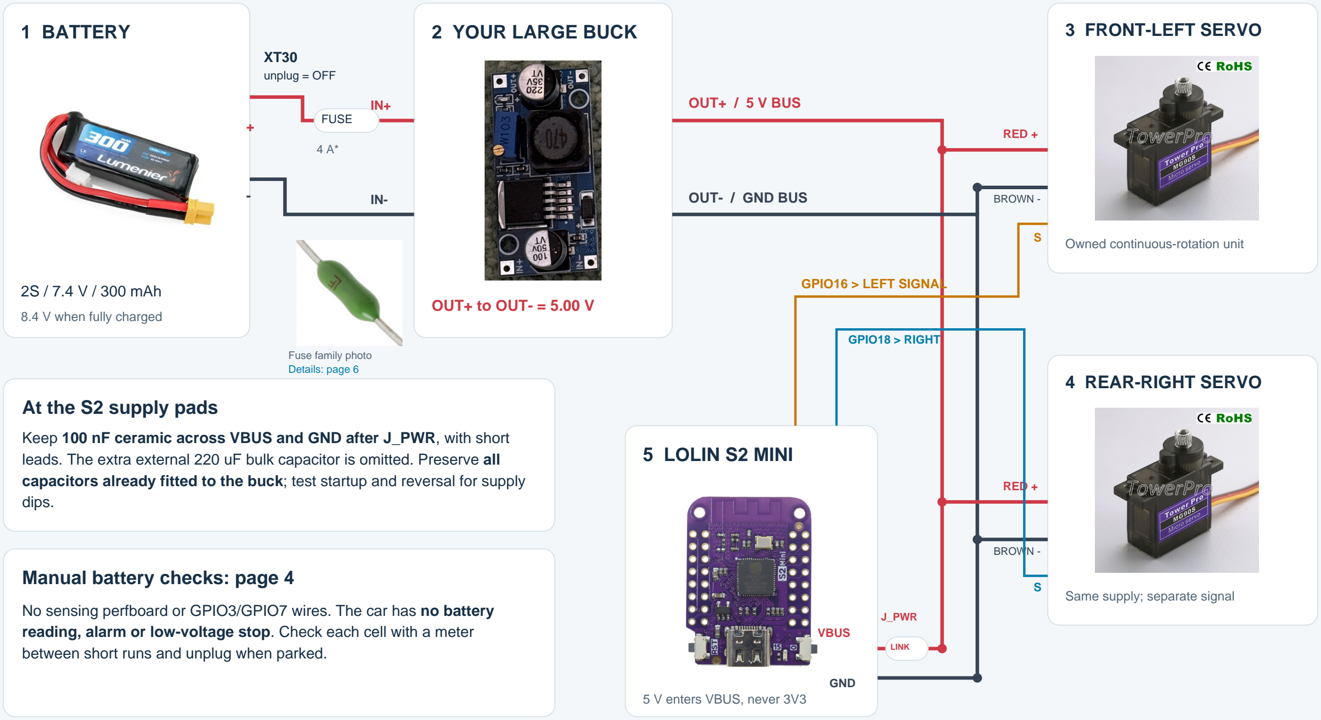
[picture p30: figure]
1 BATTERY; 2S / 7.4 V / 300 mAh; 8.4 V when fully charged; 2 YOUR LARGE BUCK; OUT+ to OUT- = 5.00 V; 3 FRONT-LEFT SERVO; Owned continuous-rotation unit; 4 REAR-RIGHT SERVO; Same supply; separate signal; 5 LOLIN S2 MINI; 5 V enters VBUS, never 3V3; XT30 unplug = OFF; FUSE; Fuse family photo Details: page 6; OUT+ / 5 V BUS; OUT- / GND BUS; RED +; BROWN -; LINK; J_PWR; VBUS; GND; GPIO16 > LEFT SIGNAL; GPIO18 > RIGHT; At the S2 supply pads; dips.; Manual battery checks: page 4

08 SEP 2026 | Unbuilt electrical prototype - verify the delivered hardware before connecting | 1 / 7

Keep 100 nF ceramic across VBUS and GND after J_PWR, with short leads. The extra external 220 uF bulk capacitor is omitted. Preserve all capacitors already fitted to the buck; test startup and reversal for supply

No sensing perfboard or GPIO3/GPIO7 wires. The car has no battery reading, alarm or low-voltage stop. Check each cell with a meter between short runs and unplug when parked.

* Fuse rating is provisional. Photos show reference servos; wire functions, not plug orientation, define the connections.

# Exactly where each wire lands

Component side facing you. S2 antenna at the top; USB-C at the bottom. Photos are not mirrored.

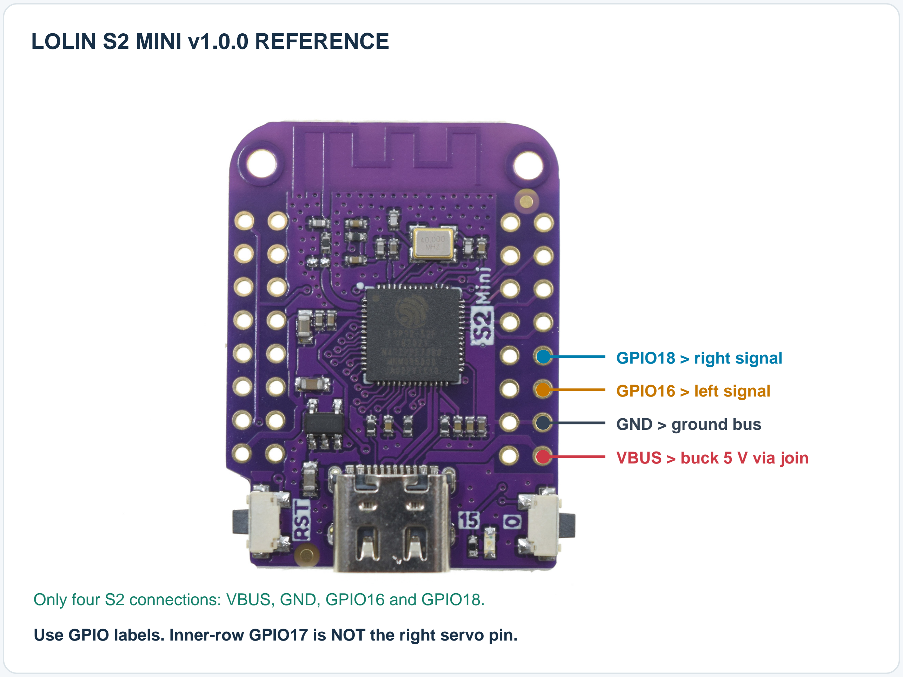
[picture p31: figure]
LOLIN S2 MINI v1.0.0 REFERENCE; GPIO18 > right signal; GPIO16 > left signal; GND > ground bus; VBUS > buck 5 V via join
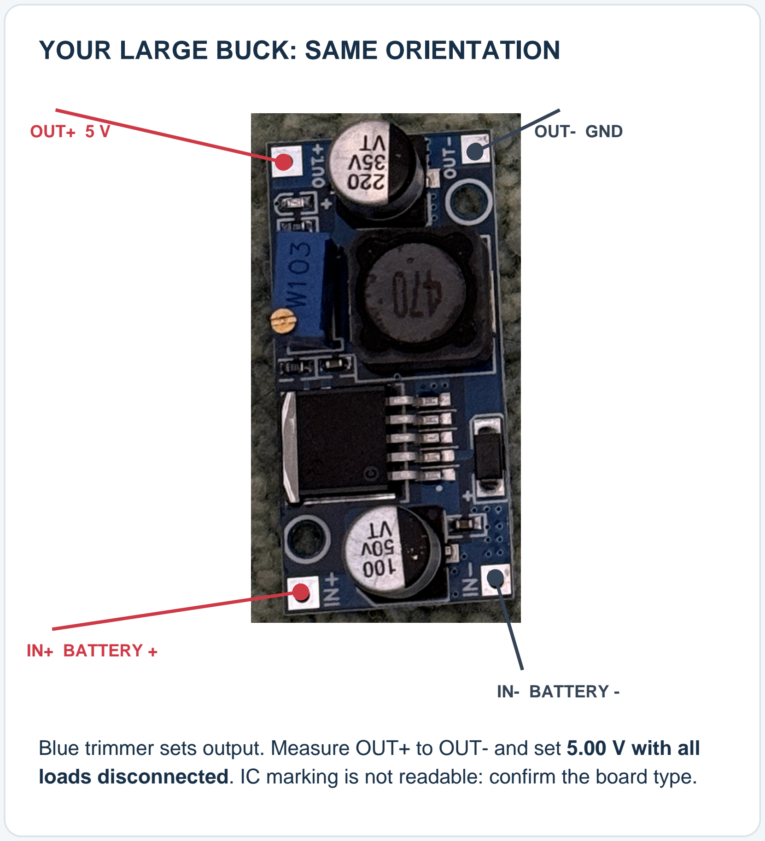
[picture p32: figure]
YOUR LARGE BUCK: SAME ORIENTATION; OUT+ 5 V; OUT- GND; IN+ BATTERY +; IN- BATTERY -

08 SEP 2026 | Unbuilt electrical prototype - verify the delivered hardware before connecting | 2 / 7

Only four S2 connections: VBUS, GND, GPIO16 and GPIO18.

Use GPIO labels. Inner-row GPIO17 is NOT the right servo pin.

Blue trimmer sets output. Measure OUT+ to OUT- and set 5.00 V with all loads disconnected. IC marking is not readable: confirm the board type.

### Soldered wiring + removable connectors

Bare S2 holes and converter pads need soldered wires or soldered headers. Use 22 AWG or thicker for the battery and main 5 V / GND paths. Servo red normally means supply; brown/black ground; orange/yellow signal. Verify your servo wires before fitting a 3-pin extension. Split its three wires to the correct nets - do not plug the whole servo lead onto random adjacent S2 pins.

# Battery, plug and converter choice

Reuse the larger buck for this prototype. A custom power PCB is not required.

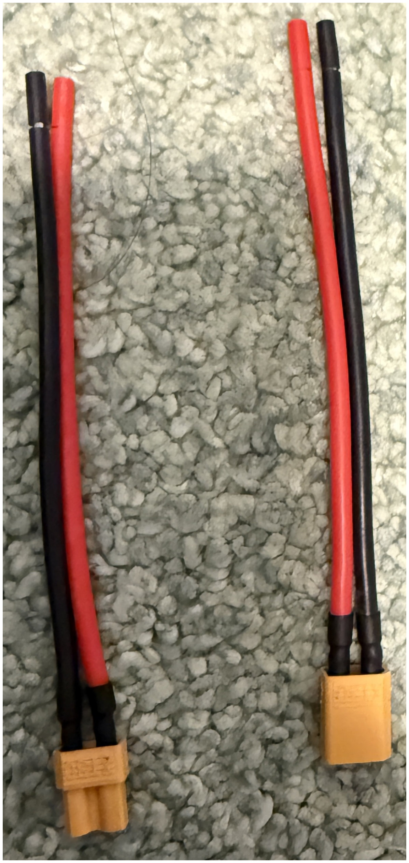
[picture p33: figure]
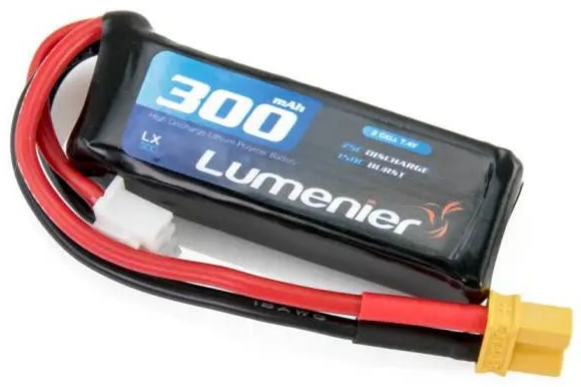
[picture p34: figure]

08 SEP 2026 | Unbuilt electrical prototype - verify the delivered hardware before connecting | 3 / 7

## BUY: LUMENIER 300

2S 75C LiPo, XT30
48 x 17 x 12 mm
18 g; 7.4 V nominal
8.4 V fully charged

$13.49; listed available
at the research snapshot.

RaceDayQuads product / purchase page (https://www.racedayquads.com/products/lumenier-300mah-2s-75c-lipo-battery-xt-30)

## YOUR YELLOW CONNECTORS

The photo establishes the XT family, but does not distinguish XT30 from XT60. Read the molded marking.

XT30: use the mating harness half.
XT60: buy an XT30 mating pigtail; a bulky adapter also works but increases footprint.

Check + / - with a meter. Housing shape or wire color alone is not proof of polarity.

## Why the large buck wins here

A 2S pack feeds a step-down converter naturally. Allowing 1.2 A per servo plus 0.4 A for the S2 gives a provisional 2.8 A at 5 V. Actual servo peaks are unknown. The LM2596 IC is rated 3 A with suitable parts and cooling; this particular board must still pass load and temperature checks at 8.4 V and 7.0 V.

### Why not the small XL63070 board?

It appears to be a TPS63070-style buck-boost module; the IC is unconfirmed. TI specifies 2 A output at 4 V in / 5 V out. That is below our provisional load. A 1S design at 14 W could also need about 5 A near 3.3
V. Smaller hardware needs current measurements first.

Battery handling and fit

12 mm is the published nominal pack height, not measured installed height: leave room for padding and lead bends. This hobby pack has no verified protection PCB. Neither owned converter provides charging, balancing or a suitable LiPo cutoff. Use a 2S balance charger and unplug the pack after each run.

# Manual battery checks

The perfboard is removed. GPIO3 and GPIO7 stay unwired. The car cannot detect a low battery.

08 SEP 2026 | Unbuilt electrical prototype - verify the delivered hardware before connecting | 4 / 7

## No automatic low-voltage protection

The fuse opens on sufficiently large overcurrent, not low voltage. Firmware has no pack reading, low-battery alarm or voltage-triggered motion stop. A joystick stop leaves the electronics powered. Unplug XT30 whenever parked.

## Measure the two cells separately

Unplug XT30 from the car. Set the multimeter to DC volts, leads in COM and V, never the current socket/range. Prefer an insulated mating balance breakout.

The three balance taps are pack negative, cell midpoint and pack positive. Each adjacent pair measures one cell; the two end taps measure the whole pack.

Verify tap order and polarity on your pack. Do not assume left/right orientation or colors. Never bridge adjacent contacts with metal probe tips.

## Short, attended trials

Start with a correctly balance-charged pack. Check both cells before and between very short runs while establishing runtime.

End the session at or below 3.7 V per cell at rest, or earlier if the pack instructions require. This is an early project stopping point, not a battery minimum or a guarantee against dips during use. At 3.5 V or lower, do not do another run.

Unplug promptly for abnormal heat, puffing, slowing or resets. Do not use those symptoms as the normal battery gauge.

## What a multimeter cannot do

Periodic checks cannot catch a weak cell or rapid voltage drop between measurements. Total pack voltage can hide an individually depleted cell. No safe fixed runtime has been measured for this car.

Before Wi-Fi updates: use a freshly balance-charged pack and lift the wheels. Firmware does not check voltage before or during upload. Longer unattended operation needs a different protection plan.

# Build, check and use

No custom PCB. This is a soldered prototype harness, not a tested plug-and-play electrical assembly.

08 SEP 2026 | Unbuilt electrical prototype - verify the delivered hardware before connecting | 5 / 7

## Wire and check in this order

1. Battery unplugged: solder the mating XT30 lead through a provisional 4 A inline fuse to IN+; negative to IN-. Insulate every joint.
2. Leave all loads disconnected. Power the buck, read OUT+ to OUT- with a multimeter and adjust to 5.00 V. Unplug before adding wires.
3. Split OUT+ and OUT- into separate servo and S2 branches. Add the 100 nF bypass at S2 VBUS/GND after J_PWR. Fit J_PWR as a removable insulated connector in the S2 VBUS feed.
4. Leave GPIO3 and GPIO7 unwired. There is no sensing circuit. Check both cells with a meter as shown on page 4.
5. With wheels lifted, test each servo, then both together. Check 5 V stability, resets and board temperature at 8.4 V and 7.0 V input. Do not hold a servo stalled.
6. Verify calibrated neutral on joystick release and signal loss. Firmware cannot detect a low battery. Establish short run intervals with manual cell checks.

## Before connecting USB to the S2

Unplug the battery, remove J_PWR, and disconnect both servo signal wires. Ground may remain connected. The S2 VBUS header is connected to USB power: battery disconnection alone can still let USB feed the servos or buck backward through the 5 V wire. Restore J_PWR and signals only after USB is removed.

## Charge outside the car

Use a 2S LiPo balance charger set for 4.20 V/cell (8.40 V pack). A conservative 1C setting for 300 mAh is 0.30 A, subject to pack instructions. Connect its XT30 main lead and 3-pin balance lead as the charger requires. A 1S USB/TP4056 charger is not compatible. Charge attended on a nonflammable surface.

POC battery checks: check both cells with your multimeter before and between short, attended test runs. Do not bridge adjacent balance contacts with probe tips. End the session when either cell reaches 3.7 V at rest. Unplug when parked. Firmware has no battery sensing, alarm or low-voltage stop; periodic checks cannot guarantee protection between measurements.

### Sources, image credits and build files

WEMOS: S2 Mini photo, board pinout and schematic (https://docs.wemos.cc/en/latest/s2/s2_mini.html)

TI: LM2596 buck datasheet (https://www.ti.com/lit/ds/symlink/lm2596.pdf)

TI: TPS63070 buck-boost datasheet (https://www.ti.com/lit/ds/symlink/tps63070.pdf)

TowerPro: MG90S reference image (not proof of continuous rotation) (https://towerpro.com.tw/product/mg90s-3/)

Battery photo: Lumenier / RaceDayQuads (page 3). Converter and connector photos: user. Third-party images are not MIT-licensed.

# What is underneath the deck?

The perfboard and extra bulk capacitor are removed. The fuse and small S2 bypass remain.

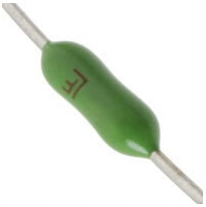
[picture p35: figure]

08 SEP 2026 | Unbuilt electrical prototype - verify the delivered hardware before connecting | 6 / 7

## F_IN: a compact fuse candidate

251-series reference photo Appearance / markings may vary

Littelfuse 0251004.MXL
PICO II 251 series

### 4 A, very fast acting

125 V DC rated
300 A DC interrupt rating

Body: 7.11 mm long,
2.80 mm maximum diameter.
Leads and insulation add space.

DigiKey: 0251004.MXL / purchase page (https://www.digikey.com/en/products/detail/littelfuse-inc/0251004-MXL/700745)

Littelfuse: specifications and mechanical drawing (https://www.littelfuse.com/assetdocs/littelfuse_fuse_251_253_datasheet.pdf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)

## Why these extra parts are here

Fuse: opens the battery-positive feed during a sufficiently large overcurrent, such as a wiring short. It is one-time use; replace after finding the fault. It is not low-battery protection or a precise 4 A current limiter.

No perfboard: the voltage divider, transistors, sensing resistors and ADC filter are removed. There are no GPIO3 or GPIO7 wires. Battery checks are manual; no electronic low-voltage protection remains.

Bypass: retain the small 100 nF ceramic at S2 VBUS/GND after J_PWR and the buck's fitted capacitors. The extra 220 uF part is omitted; supply stability still needs a load test.

### Where the fuse connects

XT30 harness + | F_IN fuse | VBAT_SW: fused battery positive to buck IN+

Assembly: put the fuse close to the battery connector in the positive harness lead. This axial candidate is soldered inline and insulated with strain relief; it does not require a bulky cartridge holder. Either fuse lead can face the battery. Keep motor current in the insulated power harness, away from S2 GPIOs.

Still provisional: validate 4 A against measured startup current, wire size and fault current. The updated Blender body follows the axial candidate; lead bends, insulation and loose cradle retention still need a fit check. Photo: Littelfuse / DigiKey, reference image supplied with this product listing.

Buck 5 V goes straight to ESP32 VBUS.

J_PWR is our label for a removable join in that wire. It is not a board, regulator, or ESP32 pin.

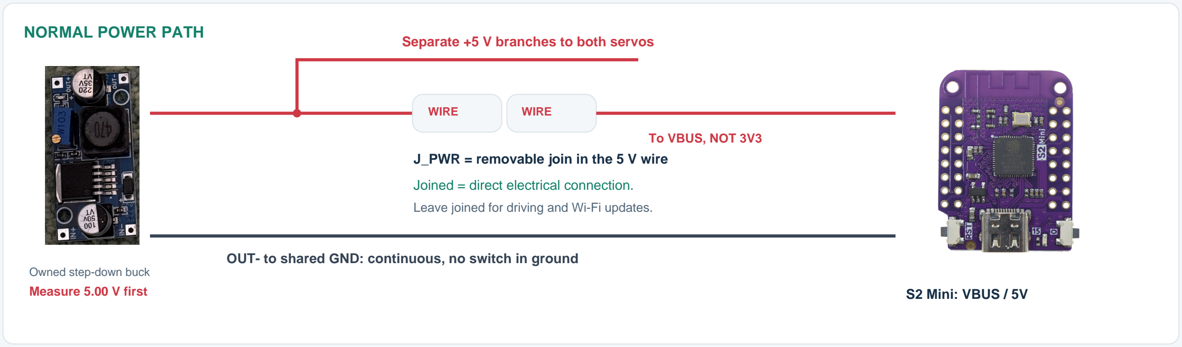
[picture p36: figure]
NORMAL POWER PATH; Owned step-down buck; Measure 5.00 V first; S2 Mini: VBUS / 5V; Separate +5 V branches to both servos; WIRE; J_PWR = removable join in the 5 V wire; Joined = direct electrical connection.; To VBUS, NOT 3V3

08 SEP 2026 | Unbuilt electrical prototype - verify the delivered hardware before connecting | 7 / 7

Leave joined for driving and Wi-Fi updates.

OUT- to shared GND: continuous, no switch in ground

## Driving on your home Wi-Fi

Set your network in web.private.h. Open http://spy-car.local/ on a computer or phone on the same network. Your computer keeps internet access. Battery, buck, J_PWR and servos stay connected; no USB cable.

## Wireless update mode: current firmware

Lift the wheels. Boot normally, then hold BOOT/0 for 3 seconds. Driving locks off. Join SpyCar-Update; open http://192.168.4.1/update. Login: admin. Use your configured password for both Wi-Fi and login. Keep USB unplugged.

### USB recovery and the next software step

USB initial setup / recovery: unplug XT30, separate J_PWR and unplug both servo signals first. Ground may remain connected. Planned, not yet implemented: updates over home Wi-Fi at spy-car.local/update, with SpyCar-Update as fallback. The wiring already supports both approaches; no extra switch is needed.

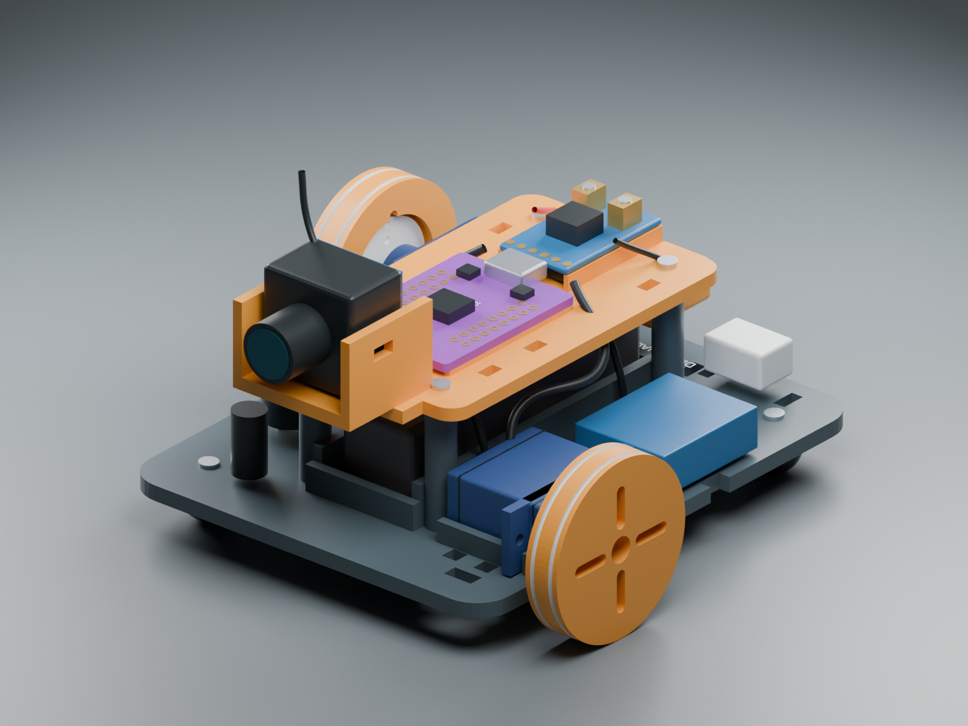
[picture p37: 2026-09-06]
images/assembly.png

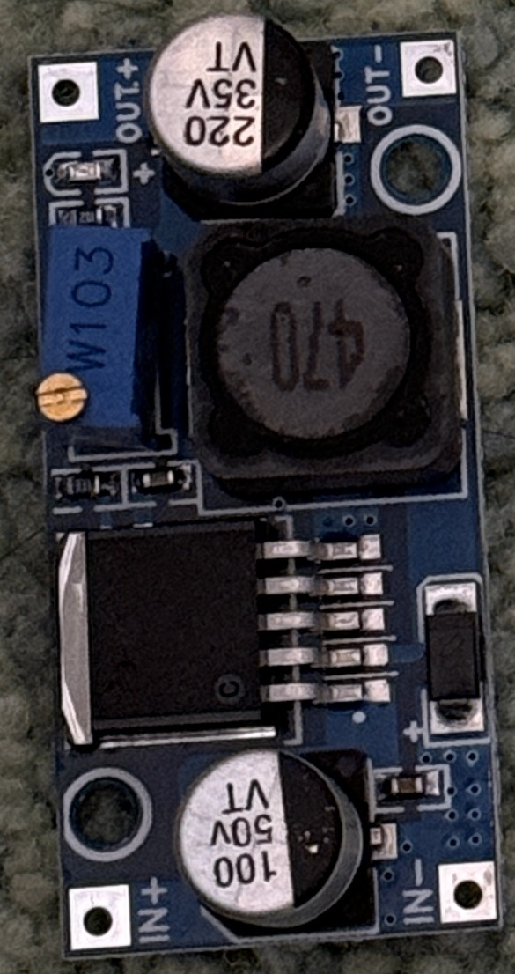
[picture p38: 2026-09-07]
electronics/guide-assets/owned-buck.jpg

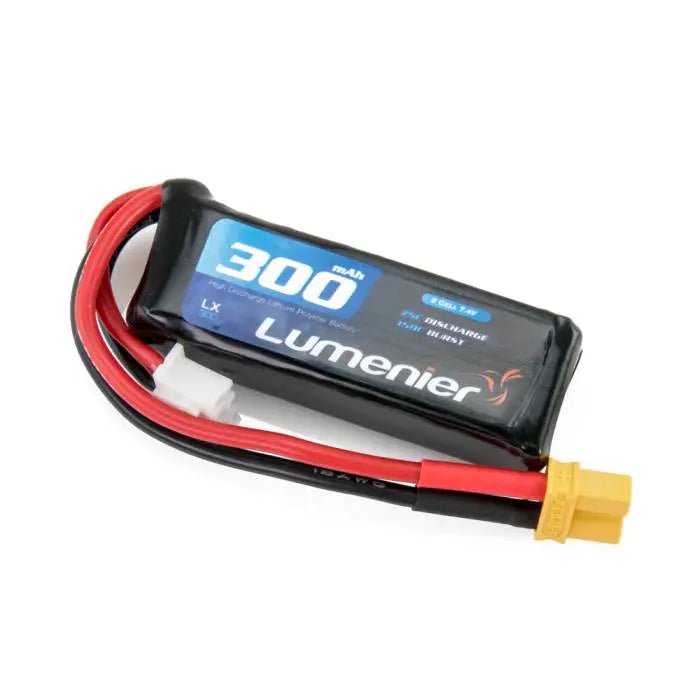
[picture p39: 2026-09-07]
electronics/guide-assets/battery.webp

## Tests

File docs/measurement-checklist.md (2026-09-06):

# Measurements needed to turn the reference CAD into an exact fit

The component models are nominal reference models. Fill this sheet from the actual parts before locking mounting holes and printing the complete car. A cheap digital caliper, ruler, and multimeter are useful additions to the printer and soldering kit. Record millimetres unless stated otherwise.

## MG90S units (measure both separately)

| Measurement | Left servo | Right servo | Why it matters |
| --- | --- | --- | --- |
| Vendor / label / purchase link | | | Distinguishes continuous variants and clones |
| Body length excluding ears | | | Cradle fit |
| Body width | | | Cradle fit |
| Rectangular body height | | | Do not confuse with total shaft height |
| Total height to shaft top, no horn | | | Wheel axle and hub clearance |
| Mounting-ear overall length | | | Bracket envelope |
| Mounting-ear thickness and vertical offset | | | Bracket seating |
| Ear hole diameter and center spacing | | | Fastener locations |
| Shaft center to near end of body | | | Wheel position |
| Shaft center to side face | | | Wheel position |
| Boss diameter and height | | | Wheel/horn clearance |
| Horn shape, diameter or arm length | | | Printed wheel pocket |
| Horn thickness and center boss depth | | | Wheel offset and retaining-screw access |
| Useful horn hole diameters / radial positions | | | Wheel fasteners |
| Original center-screw length and head diameter | | | Engagement and tool access |
| Cable exit position, plug size, cable length | | | Routing and strain relief |
| Weight with usable cable and horn (g) | | | Balance and battery estimate |

Place a ruler in photographs of the top, bottom, and side if recording visual detail. Photographs help model features; calipers establish fit-critical dimensions. Do not infer precise millimetres from a perspective photograph.

## S2 mini

| Measurement | Actual value |
| --- | --- |
| Exact manufacturer and PCB revision | |
| PCB length, width, thickness | |
| Corner shape / radius | |
| Header installation: bare, pins, sockets | |
| Header pitch and row offsets | |
| Tallest part above and below PCB | |
| USB-C overhang, width, height | |
| Cable plug envelope and usable insertion direction | |
| Reset and boot button clearance | |
| Antenna end and nearby keep-clear region | |

Use the [official v1.0.0 dimension drawing](https://www.wemos.cc/en/latest/_static/files/dim_s2_mini_v1.0.0.pdf) only after confirming the board matches it. The official board size is a good reference; clone connectors, buttons, and header heights may differ.

## Battery, power parts, and FPV module

| Measurement or check | Actual value |
| --- | --- |
| Battery model and cell count | |
| Battery maximum stated dimensions including wrap | |
| Actual dimensions without squeezing the pouch | |
| Lead exit, connector type, polarity, cable length | |
| Balance connector access if a 2S pack is used | |
| Charger model and supported chemistry / cell count | |
| Regulator model, board dimensions, underside protrusions | |
| Switch and fuse-holder body / panel dimensions | |
| Camera model and voltage range printed on product | |
| Camera PCB, lens barrel and connector envelopes | |
| VTX board and antenna envelope | |
| Camera view unobstructed by body or wheels | |

Do not substitute a battery because its nominal voltage and connector look similar. Chemistry, cell count, discharge rating, charge method, and connector polarity must match the power design.

## Fit and function log

| Test | Result / change needed |
| --- | --- |
| Printer, material, nozzle, layer height | |
| Clearance coupon chosen | |
| Servo-to-bracket fit and positive restraint | |
| Horn and printed wheel concentricity | |
| Screw engagement and wheel case clearance | |
| All four ground contact heights | |
| Full assembled mass (g) | |
| Neutral pulse width for each servo (µs) | |
| Verified continuous rotation and direction | |
| Neutral, free-running, and loaded-turn current | |
| Radio-loss and deadman stop time | |
| Low-battery behavior | |
| Straight / left / right floor test | |

Leave unknown fields blank. Do not convert an unmeasured assumption into a claimed exact replica.

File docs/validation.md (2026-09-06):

# Validation and remaining physical checks

Revision 0.1 is an unbuilt design. No physical replica comparison, print fit, load test, battery runtime, camera reception or driving result is claimed.

## Digital checks

- Blender 5.2.1 LTS generated both reference and assembly `.blend` files, eight binary millimetre STLs and three renderings.
- `cad/mesh-report.json` records dimensions, closed manifold edges and positive volume for each exported part.
- `scripts/verify_artifacts.py` independently parses STL bytes, checks edge incidence, connected shells and Z=0 print placement; also checks BOM shape and relative Markdown links. Its output is `cad/artifact-report.json`.
- `scripts/validate_blender.py` checks Boolean intersections of printed parts with the modeled nominal hardware and other printed parts. Its output is `cad/clearance-report.json`. This excludes illustrative wires/details and does not certify real hardware tolerances or dynamic wheel screw clearance.
- Host C++ tests exercise the radio drive state gate: inhibition, arming, deadman, stale packets, timeout, session changes and sequence wrap. Board compilation results are recorded below after the target checks run.
- No slicing or extrusion simulation was performed. Import each STL into your own slicer and inspect layers/scale/orientation before printing.

## Before finalizing the mechanical design

1. Record the owned servo bodies, ears, output-axis positions, original horn shapes and screws in [measurement-checklist.md](measurement-checklist.md).
2. Confirm which S2 mini revision is owned and the actual header/connector heights.
3. Obtain the actual IDC-681H dimensions and permitted supply voltage. Replace the provisional camera envelope; adjust its padded cradle.
4. Check the selected fuse, connectors and completed sense board fit the reserved volumes with insulation and lead bend space.
5. Print the coupon and a single wheel. Establish the chosen screw fit and verify the horn lies flat against its wheel.
6. Check all four contact points, the full wheel/screw sweep and access to the battery disconnect. Nominal dimensions are not tolerance-stack validation.

## Before driving

Follow the staged steps in [wiring.md](../electronics/wiring.md) and [power.md](power.md). Measure 5 V regulation, backup cutoff and restart, battery ADC scale, and each cell separately. Verify the gated ADC input is not held high when board power disappears. Confirm servo neutral and direction with raised wheels and start with a current-limited supply.

Verify release-to-stop, transmitter power loss, receiver restart, stale packet behavior and battery stop. Measure straight and turning current with the full payload. Abort a stalled or overheating turn; diagonal steering requires wheel scrub and cannot be assumed to work on carpet. Check camera image/noise while driving and confirm regulator temperature with the assembled layout.

Keep the 2S pack removable for balance charging. Pack-level sensing does not detect a weak individual cell and is not a BMS. A later unsupervised or enclosed revision needs a deliberate protection design and validated thermals; none is certified by these files.

## Board compilation

Verified on macOS with Arduino CLI **1.5.2-rc.1** and Espressif Arduino-ESP32 **3.3.11**. All three checked-in sketches compiled and linked successfully with their default, disabled commissioning configuration:

| Sketch | Target FQBN | Flash bytes | Static RAM bytes |
|---|---|---:|---:|
| `receiver_s2` | `esp32:esp32:lolin_s2_mini` | 867374 | 72936 |
| `transmitter_esp32` | `esp32:esp32:esp32` | 889140 | 45536 |
| `servo_neutral_s2` | `esp32:esp32:lolin_s2_mini` | 301995 | 49096 |

The final receiver was rebuilt after review fixes. Host state-gate tests passed, including the exact 249/250 ms timeout boundary. No firmware was flashed to physical hardware. `TMPDIR=/private/tmp` was used for the macOS sandbox compilation environment; normal installations can follow the portable commands in [firmware/README.md](../firmware/README.md).

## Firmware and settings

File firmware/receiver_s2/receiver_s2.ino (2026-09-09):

// Original MIT-licensed prototype. Requires Arduino-ESP32 3.x.
#include <Arduino.h>
#include <WiFi.h>
#include <esp_now.h>
#include <esp_wifi.h>
#include <freertos/FreeRTOS.h>
#include <freertos/queue.h>
#include <atomic>
#include <SpyCarProtocol.h>
#include "maintenance_gate.h"
#include "ota_service.h"
#include "web_control.h"
#if __has_include("config.private.h")
#include "config.private.h"
#else
#include "config.h"
#endif

#if !CONFIG_IDF_TARGET_ESP32S2
#error "Select LOLIN S2 MINI for this receiver."
#endif

struct Received {
  spycar::Packet packet;
  uint32_t time;
};
QueueHandle_t receiveQueue;
std::atomic<bool> receiveOverflow{false};
spycar::DriveGate drive;
bool radioReady = false;
std::atomic<bool> maintenanceActive{false};
spycar::MaintenanceGate maintenance;
CarUpdater updater;
WebControl webControl;
std::atomic<bool> webStopRequested{false};
bool pwmReady = false;
bool outputFault = false;
int leftPulse = LEFT_NEUTRAL_US;
int rightPulse = RIGHT_NEUTRAL_US;

bool keyPresent(const uint8_t *key) {
  uint8_t combined = 0;
  for (int i = 0; i < 16; ++i) combined |= key[i];
  return combined != 0;
}

bool queueWebCommand(const spycar::Packet &packet, uint32_t issuedAt) {
  if (maintenanceActive || !receiveQueue) return false;
  Received received{packet, issuedAt};
  if (xQueueSend(receiveQueue, &received, 0) == pdTRUE) return true;
  receiveOverflow = true;
  return false;
}

void requestWebStop() { webStopRequested = true; }

void onReceive(const esp_now_recv_info_t *info, const uint8_t *data, int length) {
  if (WEB_CONTROL_ENABLED || maintenanceActive || !info || length != sizeof(spycar::Packet) ||
      memcmp(info->src_addr, TRANSMITTER_MAC, 6) != 0) return;
  Received received;
  memcpy(&received.packet, data, sizeof(received.packet));
  if (!spycar::valid(received.packet)) return;
  received.time = millis();
  // ESP-NOW invokes this from its Wi-Fi task; leave work to the main loop.
  if (xQueueSend(receiveQueue, &received, 0) != pdTRUE) receiveOverflow = true;
}

void writePulse(uint8_t pin, int microseconds) {
  const uint32_t duty = ((uint32_t)microseconds * 16384UL + 10000UL) / 20000UL;
  if (!ledcWrite(pin, duty)) {
    drive.stop();
    pwmReady = false;
    outputFault = true;
    ledcDetach(LEFT_SERVO_PIN);
    ledcDetach(RIGHT_SERVO_PIN);
    pinMode(LEFT_SERVO_PIN, OUTPUT);
    pinMode(RIGHT_SERVO_PIN, OUTPUT);
    digitalWrite(LEFT_SERVO_PIN, LOW);
    digitalWrite(RIGHT_SERVO_PIN, LOW);
  }
}

void stopNow() {
  leftPulse = LEFT_NEUTRAL_US;
  rightPulse = RIGHT_NEUTRAL_US;
  if (pwmReady) writePulse(LEFT_SERVO_PIN, leftPulse);
  if (pwmReady) writePulse(RIGHT_SERVO_PIN, rightPulse);
}

int approach(int current, int target) {
  return current + constrain(target - current, -SLEW_US_PER_20MS, SLEW_US_PER_20MS);
}

void attachNeutral() {
  if (!SERVO_CALIBRATION_CONFIRMED) return;
  const bool leftOk = ledcAttach(LEFT_SERVO_PIN, 50, 14);
  const bool rightOk = ledcAttach(RIGHT_SERVO_PIN, 50, 14);
  pwmReady = leftOk && rightOk;
  if (!pwmReady) {
    outputFault = true;
    ledcDetach(LEFT_SERVO_PIN);
    ledcDetach(RIGHT_SERVO_PIN);
    pinMode(LEFT_SERVO_PIN, OUTPUT);
    pinMode(RIGHT_SERVO_PIN, OUTPUT);
    digitalWrite(LEFT_SERVO_PIN, LOW);
    digitalWrite(RIGHT_SERVO_PIN, LOW);
  }
  stopNow();
}

void enterMaintenance() {
  maintenanceActive = true;
  drive.inhibit(true);
  stopNow();
  esp_now_unregister_recv_cb();
  esp_now_deinit();
  radioReady = false;
  if (receiveQueue) xQueueReset(receiveQueue);
  receiveOverflow = false;
  if (WEB_CONTROL_ENABLED && !webControl.stop()) {
    Serial.println("Could not stop control server; staying parked without updater.");
    return;
  }
  updater.begin();
}

void setup() {
  vTaskPrioritySet(nullptr, 3); // Keep motor stops ahead of the HTTP task (2).
  pinMode(OTA_BUTTON_PIN, INPUT_PULLUP);
  pinMode(LEFT_SERVO_PIN, OUTPUT);
  pinMode(RIGHT_SERVO_PIN, OUTPUT);
  digitalWrite(LEFT_SERVO_PIN, LOW);
  digitalWrite(RIGHT_SERVO_PIN, LOW);
  Serial.begin(115200); // No indefinite USB-serial wait: failsafe loop must run.
#if ARDUINO_USB_CDC_ON_BOOT
  Serial.setTxTimeoutMs(0); // A full USB monitor buffer must not delay stopping.
#endif
  Serial.println("Manual battery checks required: no voltage sensing or low-voltage cutoff.");
  // Known neutral must not depend on successful radio pairing.
  attachNeutral();
  receiveQueue = xQueueCreate(8, sizeof(Received));
  if (WEB_CONTROL_ENABLED) {
    if (receiveQueue) webControl.begin();
    return; // Browser control replaces the handheld's pairing/radio gates.
  }
  WiFi.mode(WIFI_STA);
  WiFi.setSleep(false);
  Serial.printf("Receiver station MAC: %s\n", WiFi.macAddress().c_str());
  if (!receiveQueue || !PAIRING_CONFIGURED || !keyPresent(ESPNOW_PMK) ||
      !keyPresent(ESPNOW_LMK)) {
    Serial.println("Drive disabled: configure both MAC addresses and private keys.");
    return;
  }
  if (esp_wifi_set_channel(WIFI_CHANNEL, WIFI_SECOND_CHAN_NONE) != ESP_OK ||
      esp_now_init() != ESP_OK || esp_now_set_pmk(ESPNOW_PMK) != ESP_OK) return;
  esp_now_peer_info_t peer = {};
  memcpy(peer.peer_addr, TRANSMITTER_MAC, 6);
  memcpy(peer.lmk, ESPNOW_LMK, 16);
  peer.channel = WIFI_CHANNEL;
  peer.ifidx = WIFI_IF_STA;
  peer.encrypt = true;
  if (esp_now_add_peer(&peer) != ESP_OK ||
      esp_now_register_recv_cb(onReceive) != ESP_OK) return;
  radioReady = true;
}

void loop() {
  const uint32_t now = millis();
  static uint32_t lastServo = 0, lastStatus = 0;
  if (maintenance.update(digitalRead(OTA_BUTTON_PIN) == LOW, now)) {
    enterMaintenance();
  }
  if (maintenance.active) {
    stopNow(); // Hardware PWM holds calibrated neutral during HTTP/flash work.
    updater.tick();
    delay(1);
    return; // No drive processing, including after update failures/timeouts.
  }
  if (WEB_CONTROL_ENABLED) webControl.tick();
  if (webStopRequested.exchange(false)) {
    drive.stop();
    stopNow();
    if (receiveQueue) xQueueReset(receiveQueue);
  }
  drive.inhibit(maintenance.inhibit || !(WEB_CONTROL_ENABLED ? webControl.ready() : radioReady) ||
                !pwmReady || outputFault);
  drive.tick(now);
  const bool queueFault = receiveOverflow.exchange(false);
  if (queueFault) {
    drive.stop();
    stopNow();
    xQueueReset(receiveQueue);
  }
  Received received;
  // Bound callback work so a busy sender cannot starve failsafes.
  // After overflow, accept no command in this iteration, including a rearm.
  for (int processed = 0; !queueFault && receiveQueue && processed < 8 &&
       xQueueReceive(receiveQueue, &received, 0) == pdTRUE; ++processed) {
    if (WEB_CONTROL_ENABLED && received.packet.session != webControl.session()) continue;
    drive.accept(received.packet, received.time, millis());
    // Process every release packet, even if a press follows in the same batch.
    if (!drive.armed) stopNow();
  }
  drive.tick(millis()); // Recheck the boundary immediately before any PWM write.
  if (webStopRequested.exchange(false)) {
    drive.stop();
    if (receiveQueue) xQueueReset(receiveQueue);
  }
  if (!drive.armed) {
    stopNow();
  } else if (now - lastServo >= 20) {
    lastServo = now;
    int left = drive.throttle - drive.steering;
    int right = drive.throttle + drive.steering;
    if (WEB_CONTROL_ENABLED) {
      const auto mix = spycar::mixJoystick(-drive.steering, drive.throttle);
      left = mix.left;
      right = mix.right;
    } else {
      const int maximum = max(1000, max(abs(left), abs(right)));
      left = left * 1000 / maximum;
      right = right * 1000 / maximum;
    }
    leftPulse = approach(leftPulse, LEFT_NEUTRAL_US + LEFT_DIRECTION * left * MAX_DEVIATION_US / 1000);
    rightPulse = approach(rightPulse, RIGHT_NEUTRAL_US + RIGHT_DIRECTION * right * MAX_DEVIATION_US / 1000);
    if (pwmReady) writePulse(LEFT_SERVO_PIN, leftPulse);
    if (pwmReady) writePulse(RIGHT_SERVO_PIN, rightPulse);
  }
  if (WEB_CONTROL_ENABLED) {
    const auto state = maintenance.inhibit ? WebDriveState::Maintenance :
      outputFault ? WebDriveState::OutputFault :
      !SERVO_CALIBRATION_CONFIRMED ? WebDriveState::ServoSetup : WebDriveState::Ready;
    webControl.status(state, drive.armed);
  }
  if (now - lastStatus >= 1000) {
    lastStatus = now;
    Serial.printf("Battery=manual-check armed=%d radio=%d PWM=%d MAC=%s\n",
                  drive.armed, radioReady, pwmReady,
                  WiFi.macAddress().c_str());
  }
  delay(1);
}

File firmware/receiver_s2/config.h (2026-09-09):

#pragma once
#include <stdint.h>

// Commission with wheels lifted. Never publish your private pairing keys.
constexpr bool PAIRING_CONFIGURED = false;
constexpr uint8_t TRANSMITTER_MAC[6] = {0, 0, 0, 0, 0, 0};
constexpr uint8_t WIFI_CHANNEL = 1;
constexpr uint8_t ESPNOW_PMK[16] = {};
constexpr uint8_t ESPNOW_LMK[16] = {};

// False leaves PWM pins LOW and does not attach LEDC. Verify your servo's
// missing-signal behavior; the XT30 disconnect is the definitive stop.
constexpr bool SERVO_CALIBRATION_CONFIRMED = false;
constexpr uint8_t LEFT_SERVO_PIN = 16;
constexpr uint8_t RIGHT_SERVO_PIN = 18;
constexpr int LEFT_NEUTRAL_US = 1500;
constexpr int RIGHT_NEUTRAL_US = 1500;
constexpr int LEFT_DIRECTION = 1;
constexpr int RIGHT_DIRECTION = -1;
constexpr int MAX_DEVIATION_US = 180;  // Conservative initial speed range.
constexpr int SLEW_US_PER_20MS = 8;    // Emergency stops bypass this ramp.

// This POC has no battery sensing hardware. GPIO3 and GPIO7 are unconnected.
// Check both LiPo cells with a multimeter before/between short attended runs;
// firmware cannot warn about low voltage or disconnect the battery.

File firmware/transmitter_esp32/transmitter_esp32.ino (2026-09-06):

// Original MIT-licensed prototype. Requires Arduino-ESP32 3.x.
#include <Arduino.h>
#include <WiFi.h>
#include <esp_now.h>
#include <esp_wifi.h>
#include <esp_system.h>
#include <SpyCarProtocol.h>
#if __has_include("config.private.h")
#include "config.private.h"
#else
#include "config.h"
#endif

#if !CONFIG_IDF_TARGET_ESP32
#error "This joystick pinout targets an original ESP32 DevKit."
#endif

bool radioReady = false;
uint32_t session = 0;
uint32_t sequence = 0;

bool keyPresent(const uint8_t *key) {
  uint8_t combined = 0;
  for (int i = 0; i < 16; ++i) combined |= key[i];
  return combined != 0;
}

int readAxis(int raw, int minimum, int center, int maximum) {
  if (raw > center + JOYSTICK_DEADZONE)
    return constrain((raw - center - JOYSTICK_DEADZONE) * 1000 /
                     max(1, maximum - center - JOYSTICK_DEADZONE), 0, 1000);
  if (raw < center - JOYSTICK_DEADZONE)
    return constrain((raw - center + JOYSTICK_DEADZONE) * 1000 /
                     max(1, center - JOYSTICK_DEADZONE - minimum), -1000, 0);
  return 0;
}

void setup() {
  Serial.begin(115200);
  pinMode(DEADMAN_PIN, INPUT_PULLUP);
  analogReadResolution(12);
  analogSetPinAttenuation(THROTTLE_PIN, ADC_11db);
  analogSetPinAttenuation(STEERING_PIN, ADC_11db);
  WiFi.mode(WIFI_STA);
  WiFi.setSleep(false);
  Serial.printf("Transmitter station MAC: %s\n", WiFi.macAddress().c_str());
  if (!PAIRING_CONFIGURED || !keyPresent(ESPNOW_PMK) || !keyPresent(ESPNOW_LMK)) return;
  if (esp_wifi_set_channel(WIFI_CHANNEL, WIFI_SECOND_CHAN_NONE) != ESP_OK ||
      esp_now_init() != ESP_OK || esp_now_set_pmk(ESPNOW_PMK) != ESP_OK) return;
  esp_now_peer_info_t peer = {};
  memcpy(peer.peer_addr, RECEIVER_MAC, 6);
  memcpy(peer.lmk, ESPNOW_LMK, 16);
  peer.channel = WIFI_CHANNEL;
  peer.ifidx = WIFI_IF_STA;
  peer.encrypt = true;
  if (esp_now_add_peer(&peer) != ESP_OK) return;
  do { session = esp_random(); } while (session == 0);
  radioReady = true;
}

void loop() {
  const uint32_t now = millis();
  static uint32_t lastSend = 0, lastStatus = 0;
  const int throttleRaw = analogRead(THROTTLE_PIN);
  const int steeringRaw = analogRead(STEERING_PIN);
  const bool held = digitalRead(DEADMAN_PIN) == LOW;
  if (radioReady && now - lastSend >= 20) {
    lastSend = now;
    spycar::Packet packet = {};
    packet.magic = spycar::kMagic;
    packet.version = spycar::kVersion;
    packet.session = session;
    packet.sequence = ++sequence;
    if (JOYSTICK_CALIBRATION_CONFIRMED) {
      packet.flags = held ? spycar::kDeadman : 0;
      packet.throttle = THROTTLE_DIRECTION * readAxis(throttleRaw, THROTTLE_MIN, THROTTLE_CENTER, THROTTLE_MAX);
      packet.steering = STEERING_DIRECTION * readAxis(steeringRaw, STEERING_MIN, STEERING_CENTER, STEERING_MAX);
    }
    // Sending means queued, not confirmed delivered; receiver enforces timeout.
    esp_now_send(RECEIVER_MAC, reinterpret_cast<const uint8_t *>(&packet), sizeof(packet));
  }
  if (now - lastStatus >= 1000) {
    lastStatus = now;
    Serial.printf("joystick=%d,%d deadman=%d configured=%d radio=%d MAC=%s\n",
                  throttleRaw, steeringRaw, held, JOYSTICK_CALIBRATION_CONFIRMED,
                  radioReady, WiFi.macAddress().c_str());
  }
  delay(1);
}

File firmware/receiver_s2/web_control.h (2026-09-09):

#pragma once
#include <ESPmDNS.h>
#include <esp_http_server.h>
#include <esp_random.h>
#include <unistd.h>
#include <atomic>
#include "web_control_protocol.h"
#include "web_assets.h"
#if __has_include("web.private.h")
#include "web.private.h"
#else
#include "web_config.h"
#endif

bool queueWebCommand(const spycar::Packet &packet, uint32_t issuedAt);
void requestWebStop();

enum class WebDriveState { Ready, ServoSetup, OutputFault, Maintenance };

class WebControl {
 public:
  void begin() {
    station_ = strlen(WEB_WIFI_SSID) != 0;
    if (station_) {
      WiFi.mode(WIFI_STA);
      WiFi.setHostname(WEB_HOSTNAME);
      WiFi.setAutoReconnect(true);
      WiFi.begin(WEB_WIFI_SSID, WEB_WIFI_PASSWORD);
      Serial.println("Joining configured Wi-Fi for browser control.");
    } else {
      const size_t length = strlen(OTA_PASSWORD);
      if (length < 12 || length > 63) {
        Serial.println("Browser AP disabled: set OTA_PASSWORD in ota.private.h.");
        return;
      }
      WiFi.mode(WIFI_AP);
      WiFi.softAPConfig(IPAddress(192,168,4,1), IPAddress(192,168,4,1), IPAddress(255,255,255,0));
      if (!WiFi.softAP(WEB_SSID, OTA_PASSWORD, 1, false, 2)) return;
    }
    configured_ = true;
    WiFi.setSleep(false);
  }

  void tick() {
    if (!configured_) return;
    const bool connected = !station_ || WiFi.status() == WL_CONNECTED;
    if (!connected) {
      if (wasConnected_) requestWebStop();
      wasConnected_ = false;
      return;
    }
    wasConnected_ = true;
    if (!server_ && !failed_) startServer();
  }

  bool ready() const { return server_ && wasConnected_; }
  uint32_t session() const { return activeSession_.load(); }
  void status(WebDriveState state, bool armed) {
    state_ = state;
    armed_ = armed;
  }
  bool stop() {
    configured_ = false;
    requestWebStop();
    MDNS.end();
    if (server_ && httpd_stop(server_) != ESP_OK) return false;
    server_ = nullptr;
    return true;
  }

 private:
  httpd_handle_t server_ = nullptr;
  bool station_ = false, configured_ = false, wasConnected_ = false, failed_ = false;
  int owner_ = -1; // Used only by httpd task; session protects against fd reuse.
  std::atomic<uint32_t> activeSession_{0};
  std::atomic<WebDriveState> state_{WebDriveState::ServoSetup};
  std::atomic<bool> armed_{false};
  spycar::WebChallenge challenge_;
  uint32_t sequence_ = 0;
  uint32_t ownerLastCommand_ = 0;
  char pageToken_[33] = {};

  uint32_t randomNonzero() {
    uint32_t value;
    do { value = esp_random(); } while (!value);
    return value;
  }
  void revoke() {
    activeSession_ = randomNonzero();
    sequence_ = 0;
    challenge_.issue(0, millis());
    requestWebStop(); // Main loop services this before any movement backlog.
  }
  static WebControl &self(httpd_req_t *r) { return *static_cast<WebControl *>(r->user_ctx); }
  static void closeClient(httpd_handle_t h, int fd) {
    auto *car = static_cast<WebControl *>(httpd_get_global_user_ctx(h));
    if (car->owner_ == fd) { car->revoke(); car->owner_ = -1; }
    close(fd);
  }
  static void keepContext(void *) {} // Instance is static; httpd must not free it.

  bool allowedOrigin(httpd_req_t *r) {
    char origin[100], query[80];
    if (httpd_req_get_hdr_value_str(r, "Origin", origin, sizeof(origin)) != ESP_OK ||
        httpd_req_get_url_query_str(r, query, sizeof(query)) != ESP_OK) return false;
    const String expectedQuery = String("token=") + pageToken_;
    if (expectedQuery != query) return false;
    const String mdns = String("http://") + WEB_HOSTNAME + ".local";
    const String ip = String("http://") + (station_ ? WiFi.localIP() : WiFi.softAPIP()).toString();
    return mdns == origin || mdns + ":80" == origin || ip == origin || ip + ":80" == origin;
  }

  esp_err_t reply(httpd_req_t *r, bool reset) {
    const uint32_t token = randomNonzero();
    challenge_.issue(token, millis());
    static const char *reasons[] = {"Ready", "Calibrate servo neutral", "Output fault", "Update mode"};
    const WebDriveState state = state_.load();
    char payload[240];
    snprintf(payload, sizeof(payload),
             "{\"token\":%lu,\"ready\":%s,\"armed\":%s,\"reason\":\"%s\",\"reset\":%s}",
             (unsigned long)token, state == WebDriveState::Ready ? "true" : "false",
             armed_.load() && !reset ? "true" : "false", reasons[int(state)], reset ? "true" : "false");
    httpd_ws_frame_t frame = {};
    frame.type = HTTPD_WS_TYPE_TEXT;
    frame.payload = reinterpret_cast<uint8_t *>(payload);
    frame.len = strlen(payload);
    return httpd_ws_send_frame(r, &frame);
  }

  static esp_err_t socketHandler(httpd_req_t *r) {
    auto &car = self(r);
    const int fd = httpd_req_to_sockfd(r);
    if (r->method == HTTP_GET) {
      if (httpd_ws_get_fd_info(r->handle, fd) != HTTPD_WS_CLIENT_WEBSOCKET) return ESP_FAIL;
      if (!car.allowedOrigin(r)) {
        // IDF has already sent 101 before this handler. Close the socket;
        // do not send an HTTP error into an upgraded WebSocket connection.
        return ESP_FAIL;
      }
      if (car.owner_ != -1) {
        if (millis() - car.ownerLastCommand_ < 2000) {
          return ESP_FAIL;
        }
        // A vanished phone can leave a half-open TCP socket. Allow takeover
        // only after well beyond the drive timeout, and invalidate its session.
        httpd_sess_trigger_close(car.server_, car.owner_);
      }
      car.owner_ = fd;
      car.ownerLastCommand_ = millis();
      car.revoke();
      return ESP_OK; // Client sends 'hello' once the upgrade is complete.
    }
    if (fd != car.owner_) return ESP_FAIL;
    httpd_ws_frame_t frame = {};
    if (httpd_ws_recv_frame(r, &frame, 0) != ESP_OK) return ESP_FAIL;
    if (frame.type != HTTPD_WS_TYPE_TEXT || !frame.final || frame.len == 0 || frame.len > 48) {
      car.revoke();
      return ESP_FAIL;
    }
    char data[49] = {};
    frame.payload = reinterpret_cast<uint8_t *>(data);
    if (httpd_ws_recv_frame(r, &frame, 48) != ESP_OK) return ESP_FAIL;
    if ((frame.len == 5 && memcmp(data,"hello",5) == 0) ||
        (frame.len == 4 && memcmp(data,"stop",4) == 0)) {
      car.revoke();
      return car.reply(r, true);
    }
    spycar::WebInput input;
    const uint32_t issuedAt = car.challenge_.issuedAt;
    if (!spycar::parseWebInput(data, frame.len, input) || !car.challenge_.consume(input.token, millis())) {
      car.revoke();
      return car.reply(r, true);
    }
    spycar::Packet packet = {};
    packet.magic = spycar::kMagic;
    packet.version = spycar::kVersion;
    packet.session = car.activeSession_.load();
    packet.sequence = ++car.sequence_;
    packet.flags = input.held ? spycar::kDeadman : 0;
    packet.throttle = input.y;
    packet.steering = -input.x; // Preserve legacy packet's left-positive mix.
    if (!queueWebCommand(packet, issuedAt)) {
      car.revoke();
      return car.reply(r, true);
    }
    car.ownerLastCommand_ = millis();
    return car.reply(r, false);
  }
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

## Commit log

2026-09-06 feat: add diagonal servo FPV car prototype and build documentation
    [01_chassis.stl, 02_electronics_deck.stl, 03_camera_cradle.stl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]
2026-09-06 docs: shortlist compact camera-free power components
2026-09-07 feat: model compact opposing servo bracket in Blender
    [servo-pair-bracket.stl, servo-pair.blend]
2026-09-07 feat: add aligned bearing-supported passive wheels
    [bearing-fit-coupon.stl, bearing-retainer.stl, inner-spacer-2p8.stl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]
2026-09-07 feat: integrate printed axles and servo retention into chassis
    [axle-fit-coupon.stl, bearing-fit-coupon.stl, bearing-retainer.stl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]
2026-09-07 docs: add illustrated camera-free wiring guide and battery selection
    [camera-free-bom.csv]
2026-09-07 fix: correct photographed buck input polarity callouts
    [build_wiring_guide.py]
2026-09-07 feat: build complete camera-free Blender assembly and printed carrier
    [battery-band-tpu.stl, complete-spy-car.blend, electronics-deck.stl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]
2026-09-08 fix: verify battery envelope and add dimensioned Blender views
    [complete-spy-car.blend]
2026-09-08 docs: record independent battery audit and conflicting source dimensions
2026-09-08 docs: add fuse photo and explain under-deck sensing components
    [camera-free-bom.csv]
2026-09-08 style: remove stop button from joystick remote
2026-09-08 docs(cad): align wiring guide and power harness model
    [complete-spy-car.blend]
2026-09-09 feat: simplify car for manual battery checks
    [battery-band-tpu.stl, camera-free-bom.csv, complete-spy-car.blend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]
2026-09-09 fix(cad): model rounded fuse and clear its axial leads
    [complete-spy-car.blend, electronics-deck.stl]
2026-09-09 fix(cad): remove extra bulk capacitor and holder
    [camera-free-bom.csv, complete-spy-car.blend, electronics-deck.stl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]
2026-09-09 fix(cad): provide verified capacitor-free Blender snapshot
    [spy-car-v0.6.2-no-extra-capacitor.blend]
